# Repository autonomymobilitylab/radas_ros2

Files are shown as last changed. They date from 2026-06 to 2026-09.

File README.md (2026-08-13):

# Rugged ATV Data Acquisition System (RADAS)

### **Collaborators:**

 - [Aalto University Autonomy & Mobility Lab](https://www.aalto.fi/en/department-of-energy-and-mechanical-engineering/autonomy-mobility-lab): Joel Ventola, Otto Peltonen

# Overview

The Rugged ATV Data Acquisition System, or RADAS, is a versatile, rugged sensor rack designed to be mounted on the front cargo area of an ATV. With its modular design and small footprint, the system can also be mounted on other vehicles and platforms.

The purpose of this system is to collect real-world data for state-of-the-art (SOTA) datasets in unstructured off-road environments, such as forests and other off-road areas in Finland.

The system includes two different LiDAR sensors, three RGB cameras that provide a 170° field of view, a 9-DoF IMU, and an RTK-capable GNSS receiver. The system is also planned to be upgraded with an additional NIR (near-infrared) camera in the future.
The sensors and their specifications are listed in more detail in the table below.

### **Sensors**
 - 32-channel 360° LiDAR: [Hesai XT32M2X](https://www.hesaitech.com/product/xt16-32-32m/)
 - 128-channel dome LiDAR: [Hesai JT128](https://www.hesaitech.com/product/jt128/)
 - 3 x RGB-cameras: [Basler a2A1920-51gcBAS](https://www.baslerweb.com/en/shop/a2a1920-51gcbas/)
 - IMU: [Xsens MTi-320-3A-SK](https://www.xsens.com/sensor-modules/xsens-mti-320)
 - RTK-GNSS: [Ardusimple simpleRTK 4 Heading](https://www.ardusimple.com/product/simplertk-4-heading/)

# Guide
This guide contains information about many of the tools and procedures used during development. It does not necessarily reflect the final deployed system.

## **Prerequisites**

### **Software**
- [Ubuntu 24.04 LTS (Noble Numbat)](https://releases.ubuntu.com/noble/)
- [Docker 29.5.2, build 79eb04c](https://github.com/docker/docker-install)

### **Hardware**
- NUC/PC with adequite processing power, ram and storage space
- Network switch with 10GigE upstream and POE functionality
- Sensors listed in above table
- USB gpio breakout board and RGB led
- Power switch and power indicator led
- IP rated enclosure for electronics
- 12 to X volt converters for power
- Router for wireless access to the lan network
- Fusebox

## **Installation**
 1. Make sure you have the prerequisites listed above installed.

 2. Clone the repository and navigate to the `firmware` directory:

 ```shell
 git clone https://github.com/joevento/radas_ros2.git
 cd ./radas_ros2/firmware
 ```

 3. Create an .env with the following keys:
 ```text
 PROJECT_DIR=/full/path/to/radas_ros2/firmware/folder
 SERVICE_USER=user account to be used for systemctl
 PTP_INTERFACE=network interface for ptp
 NTRIPUSER=ntrip clients username (in finland use maanmittauslaitos username)
 NTRIPPASS=ntrip clients password (in finland use maanmittauslaitos password)
 ```

 4. Configure the NUC's network interface with the following static network settings:

    * **IP address:** `192.168.1.2`
    * **Subnet mask:** `255.255.255.0`

 5. Manually start the container to make sure everything works as intended:

 ```shell
 docker compose up --build
 ```

 6. Once the container has started successfully, navigate to `http://localhost:8080/` (or `http://192.168.1.2:8080/` when remote) to access the system's web interface. Each sensor is displayed in its own table, with a traffic light indicator in the first column showing its general status. Verify that all sensors show a green status.

 7. Once the system's functionality has been verified, stop the container using `Ctrl+C`.

 8. **(Optional)** Create an unprivileged user account under which the system will run.

 9. Regardless of whether you completed the optional step above, make sure the account used to run the system is automatically logged in at startup. This prevents the NUC from getting stuck on the login screen when the system is powered on.

    Automatic login can be enabled in the Ubuntu settings under:

    `System -> Users -> Automatic Login`

 > **Note:** If the Users page is grayed out, click the **"Unlock..."** button in the top-right corner.

 10. Once the functionality of the system has been verified manually, run the systemd service installation script from the `firmware` directory:

 ```shell
 ./install_service.sh
 ```

 The script installs and enables the systemd service responsible for starting the RADAS ROS 2 system automatically when the user logs in.

 11. Once the service has been installed successfully, restart the NUC and enter the BIOS (typically by pressing `F2` or `Del`). In the BIOS, enable automatic startup when power is restored.

     On the MS-01, this setting can be found under:

     `Advanced -> ACPI -> Restore Power on AC Power Loss`

     This ensures that the NUC boots and subsequently logs in automatically when the main power switch is turned on.

 12. Save the BIOS settings and exit. Allow the system to boot into Ubuntu, then navigate to `http://localhost:8080/` (or `http://192.168.1.2:8080/` when accessing remotely) and verify that all sensor status indicators are green.

 13. The system is now ready for use. From this point onward, it will automatically boot, log in, and start the RADAS ROS 2 system when the power switch on the side of the electrical cabinet is turned on.

 > **Note:** It has been measured that, from a cold and dark state, the system takes approximately two (2) minutes to start before data acquisition can begin.

## General Testing and Development Tools

### **Pylon Viewer Quick Start Outside of Docker**

 1. Run Pylon Viewer as root:

 ```shell
 sudo /opt/pylon/bin/pylonviewer
 ```

 2. Open the Pylon Viewer GigE Configurator:

    `Tools -> GigE Configurator`

    Select:

    `Optimize Complete System`

    Then click:

    `Configure`

 > **Note:** If Pylon Viewer does not detect the camera automatically, press `F12` or navigate to `Camera -> Add Remote GigE Camera` to add the camera manually.

 3. Reboot the system and relaunch Pylon Viewer to apply the configuration. The connected cameras should now be visible in Pylon Viewer.

### **Docker**

 1. Navigate to the `firmware` subdirectory:

 ```shell
 cd ./firmware/
 ```

 2. Build and start the Docker container in the background:

 ```shell
 docker compose up --build -d
 ```

 3. **(Optional)** To use GUI applications from inside the Docker container, allow local Docker containers to connect to the X server:

 ```shell
 xhost +local:docker
 ```

 > **Note:** When connecting to the system remotely via SSH, this command must be run on the local computer (e.g. laptop) before establishing the SSH connection.

 4. Open a shell inside the running container:

 ```shell
 docker compose exec ros2_dev /bin/bash
 ```

 ### **Starting the Main ROS 2 Package**

 1. Follow the Docker startup instructions above and open a shell inside the container.

 2. Inside the container, run:

 ```shell
 ros2 launch radas_bringup bringup.launch.py
 ```

 This launches the main RADAS ROS 2 bringup package.

 ### **LiDARs**

 #### **PandarView2**

 1. Make sure the device firewall is disabled or that the LiDAR UDP port (typically `2368`) is allowed through the firewall:

 ```shell
 sudo ufw disable
 sudo iptables -F
 ```

 > **Note:** Disconnecting and reconnecting the LiDAR may result in the firewall rules being reset, after which the port must be allowed through again.

 2. Check the IP address of the wired network interface:

 ```shell
 ip -br addr
 ```

 > **Note:** For troubleshooting or sanity-checking, you can verify that the connected LiDAR is sending UDP data using:
 >
 > `sudo tcpdump -i <NIC_device_name> -n udp port 2368`
 >
 > Alternatively, use Wireshark to inspect the network traffic.

 3. The default IP address of Hesai LiDARs is `192.168.1.201`. For models that support a web interface, navigate to this address in a browser to view and configure the LiDAR parameters.

    Models that do not support the web interface, such as the JT128, require Hesai's LidarUtilities software to view and modify their parameters.

 4. Launch PandarView2 and select `Listen for Data` (or press `Ctrl+R`). The host IP can either be set to `Any` or to the IP address of the wired network interface connected to the LiDAR.

 5. Once data is being received, import the corresponding angle correction file.

 #### **ROS 2 and RViz2**

 Use the same network configuration described in the PandarView2 section above.

 This guide does not cover creating the workspace, cloning the manufacturer's drivers/SDK, or installing ROS 2 package dependencies. Instead, it covers the most important configuration file changes required for the LiDARs.

 1. Configure the IP addresses in the LiDAR configuration file:

    - Set the **device IP address** to the address configured on the LiDAR.
    - Set the **host IP address** to the address of the wired network interface connected to the LiDAR.
    - Replace the **multicast IP address** with an empty string (`""`).

    All IP addresses should be specified as strings in the following format:

    ```text
    "192.168.1.xxx"
    ```

 2. Clear the following placeholder paths:

 ```yaml
 firetimes_path: ""
 ***
 channel_fov_filter_path: ""
 multi_fov_filter_ranges: ""
 ```

 3. Download the appropriate correction file for the LiDAR and configure its path. For example:

 ```yaml
 correction_file_path: "/home/user/hesai_ws/config/jt128_correction.csv"
 ```

 4. Make sure the required data is published through ROS 2:

 ```yaml
 ros:
    ros_frame_id: hesai_lidar
    ***
    send_packet_ros: true
    send_point_cloud_ros: true
    send_imu_ros: true
 ```

 5. Check the configured frame frequency. If it is set to `0`, change it to an appropriate value. For example:

 ```yaml
 frame_frequency: 10
 default_frame_frequency: 10.0
 ```

 6. Launch the LiDAR node and RViz2. To verify that the ROS 2 topics are available, run:

 ```shell
 ros2 topic list
 ```

 You should see LiDAR-related topics such as `/lidar_points`.

 Check the topic information and publishing frequency with:

 ```shell
 ros2 topic info /lidar_points
 ros2 topic hz /lidar_points
 ```

 `ros2 topic info /lidar_points` should return something similar to:

 ```text
 Type: sensor_msgs/msg/PointCloud2
 Publisher count: 1
 Subscription count: 0
 ```

 If `ros2 topic hz /lidar_points` does not return any data, ROS 2 is likely not receiving the LiDAR data stream.

 > **Note:** `ros2 topic hz` takes a few moments to calculate the publishing frequency, so do not expect an instantaneous result. With high data rates or large messages, the reported frequency may also be inaccurate. For troubleshooting purposes, the important thing is to verify that data is being received.

 ### **PTP**

 #### **Setting Up the NUC as a PTP Grandmaster**

 PTP is automatically configured when running:

 ```shell
 docker compose up --build -d
 ```

 The PTP service runs in a secondary container alongside the main ROS 2 container.

 To manually broadcast PTP from the device, for example for testing or troubleshooting, run:

 ```shell
 sudo ptp4l -i <device> -m -S
 ```

 The automatic PTP setup expects an `.env` file in the `./firmware` directory containing the network interface to use for PTP:

 ```text
 PTP_INTERFACE=<device>
 ```

 #### **LiDAR Timestamps**

 Both the JT128 and XT32M LiDARs use the same timestamp format in their data packets. The timestamp can be located manually from the raw packet data in Wireshark as follows:

 1. Starting from the end of the packet, locate the manufacturer magic value `42` in the raw Wireshark output.
 2. From `42`, move back 10 bytes (10 two-character hexadecimal byte values in Wireshark).
 3. The first byte represents `year - 1900`.
 4. The next five bytes represent, in order:
    `month, day, hour, minute, second`
 5. The final four bytes represent the microsecond component of the UTC timestamp.

 ### **SSH Access to the NUC**

 The MS-01 NUC is configured to accept SSH connections on the default SSH port. The connection details can be found physically on the machine.

 To connect to the NUC, use:

 ```shell
 ssh username@ip
 ```

 If X11 forwarding is required for graphical applications, add the `-X` option:

 ```shell
 ssh -X username@ip
 ```

 This guide does not cover the SSH server configuration itself, as the NUC uses a standard SSH server setup.

 #### **Syncing Local Changes During Development**

 For easier development, local changes can be pushed directly to the NUC using:

 ```shell
 ./firmware/sync_to_nuc.sh
 ```

 The script expects the following keys to be in your local .env file:
 ```
 REMOTE_USER=username on the nuc
 REMOTE_HOST=nuc ip address
 REMOTE_FIRMWARE_PATH=/full/path/to/radas_ros2/firmware/folder
 ```

 This allows changes made on the local development machine to be transferred to the NUC without first committing and pushing them through GitHub.

 This script should only be used during development and for quick testing. **Working, finalized code should always be committed to Git and pulled onto the NUC through the normal Git workflow.**

 Before pulling the finalized version on the NUC, discard changes previously transferred using the sync script:

 ```shell
 git restore .
 ```

 > **Warning:** `git restore .` discards uncommitted changes to tracked files. Make sure there are no changes on the NUC that need to be preserved before running this command.

 ### **Basler Cameras**

 Pylon Viewer can be used normally from inside the Docker container.

 For ROS 2 access to an individual Basler camera, the `pylon_ros2_camera_wrapper` package can be launched manually with:

 ```shell
 ros2 launch pylon_ros2_camera_wrapper pylon_ros2_camera.launch.py camera_id:="Basler_{pos}" config_file:="/ros2_ws/config/basler_{pos}.yaml"
 ```

 Replace `{pos}` with the position identifier of the camera.

 Running the camera wrapper this way is mainly useful for validating the broad functionality of the cameras inside ROS 2 and the container, as the standalone node does not provide much functionality by itself compared with the complete RADAS setup.

 ### **Running RADAS Automatically on Startup with systemd**

 The RADAS ROS 2 Docker stack can be started automatically using a systemd service.

 For this the `.env` file in the `firmware` directory should contain:

 ```shell
 PROJECT_DIR=/path/to/firmware/folder
 SERVICE_USER=localUser
 ```

 `PROJECT_DIR` should point to the RADAS `firmware` directory, and `SERVICE_USER` should be the local user account under which the system runs.

 #### **Installing the Service**

 Make the installation script executable and run it:

 ```shell
 chmod +x install_service.sh
 ./install_service.sh
 ```

 #### **Starting the Service Manually**

 ```shell
 sudo systemctl start radas_ros2.service
 ```

 #### **Viewing Logs**

 Follow the service logs in real time:

 ```shell
 journalctl -u radas_ros2.service -f
 ```

 #### **Restarting the Service**

 After making changes to the RADAS configuration or software, restart the service with:

 ```shell
 sudo systemctl restart radas_ros2.service
 ```

 #### **Disabling Automatic Startup**

 To prevent the service from starting automatically:

 ```shell
 sudo systemctl disable radas_ros2.service
 ```

 #### **Removing the Service**

 To completely remove the RADAS systemd service:

 ```shell
 sudo systemctl stop radas_ros2.service
 sudo systemctl disable radas_ros2.service
 sudo rm /etc/systemd/system/radas_ros2.service
 sudo systemctl daemon-reload
 ```

 ### **Status Page**

 The RADAS status page provides a web interface for monitoring sensor health, GNSS status, and controlling data recording.

 The page is normally started automatically as part of the RADAS Docker stack and can be accessed at:

 ```text
 http://localhost:8080
 ```

 or remotely from the RADAS network at:

 ```text
 http://192.168.1.2:8080
 ```

 #### **Diagnostics**

 Sensor health information is collected using the standard ROS 2 diagnostics pipeline:

```text
Sensor data / driver diagnostics
            |
            v
Sensor diagnostic nodes
            |
            v
      /diagnostics
            |
            v
 diagnostic_aggregator
            |
            v
    /diagnostics_agg
            |
            v
       RADAS Web UI
```

 Dedicated diagnostic nodes are used to normalize the status of the different sensor types before the information is passed to the diagnostic aggregator.

 The main sensor status table displays:

 - Traffic-light status indicator
 - Sensor name
 - Health level
 - Measured publishing frequency and expected frequency
 - Additional diagnostic details

 The traffic-light indicators represent:

 - 🟢 **Good**
 - 🟡 **Warning**
 - 🔴 **Error**
 - ⚫ **Stale / no current data**

 The expected sensor frequencies used by the status page are:

 ```text
 LiDAR:   10 Hz
 Camera:  10 Hz
 IMU:   100 Hz (fused)
 GNSS:    10 Hz
 ```

 For sensors with frequency information available, the web UI performs an additional check against the expected frequency:

 - **≥ 90%** of expected frequency: Good
 - **70–90%** of expected frequency: Warning
 - **≤ 70%** of expected frequency: Error

 The displayed health level is the more severe result of the diagnostic node's reported status and this frequency check.

 #### **Sensor Diagnostics**

 The cameras, LiDARs, IMU, and GNSS use separate diagnostic nodes.

 The **camera diagnostics** monitor the image streams of all three Basler cameras and combine their measured frame rate with the availability diagnostics produced by the Basler driver.

 The **LiDAR diagnostics** monitor the point cloud topics of both Hesai LiDARs and report their publishing frequency and stream status.

 The **IMU diagnostics** monitor the XSens IMU data stream and its publishing frequency.

 The **GNSS diagnostics** monitor the Septentrio GNSS receiver separately and provide more detailed positioning information to the web interface.

 #### **GNSS Status**

 GNSS information is displayed in a dedicated table containing:

 - Overall GNSS status
 - Positioning mode/status
 - Satellites used and visible
 - Latitude and longitude
 - Altitude
 - HDOP and PDOP
 - RF interference status
 - Spoofing status

 The GNSS diagnostic status also takes the positioning mode and availability of the required GNSS data streams into account. Detected interference or spoofing causes the GNSS diagnostic state to report an error.

 #### **System Status Indicator**

 In addition to the web interface, RADAS uses a physical status light connected through an FTDI GPIO interface.

 The light represents the overall diagnostic state of the system:

 - 🟢 **Green:** System OK
 - 🟡 **Yellow:** Warning
 - 🔴 **Red:** Error
 - 🔵 **Blue:** Diagnostics stale or unavailable

 The overall state is determined from the sensor and GNSS diagnostic states.

 #### **Recording Controls**

 The status page provides four controls for the ROS 2 system recorder:

 - **Start Recording**
 - **Pause Recording**
 - **Resume Recording**
 - **Stop Recording**

 These buttons communicate with the following ROS 2 services:

 ```text
 /system_recorder/record
 /system_recorder/pause
 /system_recorder/resume
 /system_recorder/stop
 ```

 The page also displays the current recording state and reports if a recorder request fails or the required ROS 2 service is unavailable.

 #### **Running the Status Page Manually**

 For development and testing, the web interface can be started manually.

 1. Create and activate a Python virtual environment:

 ```shell
 python3 -m venv .venv
 source .venv/bin/activate
 ```

 2. Install the required dependencies:

 ```shell
 pip install -r src/requirements.txt
 ```

 3. Make sure the ROS 2 environment and RADAS workspace are sourced:

 ```shell
 source /opt/ros/$ROS_DISTRO/setup.bash
 source install/setup.bash
 ```

 4. Start the diagnostic aggregator:

 ```shell
 ros2 run diagnostic_aggregator aggregator_node \
   --ros-args \
   --params-file diagnostic_aggregator.yaml
 ```

 5. Start the web server from another ROS-sourced terminal:

 ```shell
 python3 -m uvicorn src.webUI.app:app --host 0.0.0.0 --port 8080
 ```

 6. If accessing the web interface remotely, make sure TCP port `8080` is allowed through the firewall:

 ```shell
 sudo iptables -I INPUT 5 -p tcp --dport 8080 -j ACCEPT
 ```

 7. Open the web interface:

 ```text
 http://localhost:8080
 ```

 or, when accessing the NUC remotely:

 ```text
 http://192.168.1.2:8080
 ```

 #### **Troubleshooting**

 Check that raw diagnostics are being published:

 ```shell
 ros2 topic echo /diagnostics --once
 ```

 Check the output of the diagnostic aggregator:

 ```shell
 ros2 topic echo /diagnostics_agg --once
 ```

 The data currently received by the web UI can also be inspected directly:

 ```shell
 curl http://localhost:8080/diagnostics
 ```

 Other useful commands include:

 ```shell
 ros2 node list
 ros2 topic list
 ros2 topic hz <topic_name>
 ros2 service list
 ```

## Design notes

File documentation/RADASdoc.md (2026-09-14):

___
# RADAS user manual
This document is intended for the future use and development of the RADAS sensor rack by new users. This document is intended to fill the gaps left by the project README by serving as a general document on RADAS rather than a short bulletpoint list of setup steps. 

___
# Overview
The Rugged ATV Data Acquisition System (or RADAS) is a modular, plug-and-play sensor solution intended for capturing data in unstructured, forested areas. The purpose of this document is to provide a new user of the system with the expertise and know-how to initialize, operate and troubleshoot the system. 

The system is comprised of a central PC/NUC, 6 ethernet devices connected via a switch and 3 USB-devices. The devices used are:

| Device name | Device type | Connection to NUC |
| --- | --- | --- |
| Ubiquiti UniFi Flex 2.5G PoE | Switch | SFP |
| Basler a2A1920-51gcBAS | RGB Camera | RJ45 |
| Basler a2A1920-51gcBAS | RGB Camera | RJ45 |
| Basler a2A1920-51gcBAS | RGB Camera | RJ45 |
| Hesai XT32M2X | Hemispherical LIDAR  | RJ45 |
| Hesai JT128 | Dome LIDAR | RJ45 |
| Xsens MTi-320-3A-SK | IMU | USB |
| FTDI UM232H | USB to GPIO breakout | USB |
| Ardusimple SimpleRTK4 H | RTK GNSS-module | USB |

___
# Usage
### Powering the system
==TODO:== Attach pictures to all the steps described/of the full electrical connection diagram
The sensor rack only has 2 required connections to function: DC + and DC -. Powering the sensor rack happens via a DC input source, which can be a bench supply or an automotive auxiliary socket for example. The system accepts **12 V** at **20 A max**. 
>**Note:** the sensor rack browns out at around 9 V. As a result, it's critical that your DC source is stable and not susceptible to fluctuations. 

> **Note:** It is possible to power all the main components via their original AC adapters in troubleshooting scenarios. These AC adapters are not attached to the system, but they can be found at the lab instead. Doing this will bypass most of the elements, such as main power switch, power indicator lights and fusing described below

After the power has been connected, turn the main power switch from the position **OFF** to **ON** ==PICTURE HERE==

The system being powered should be indicated by the main power led turning on ==PICTURE HERE==

> **Troubleshoot:** If the main power led does not turn on or the rest of the system lacks all signs of life (LIDARs aren't audibly spinning, status led remains off) , check the main 20 A fuse inside the electrical cabinet. If it's blown, replace it. In other cases, check your power supply and finally change to powering the system via the AC adapters. 
### Recording via the provided Web UI
The ROS2 rosbag functionality is used to implement sensor output data recording. The recording is controlled via the Web UI with the labeled buttons on top of the page. Functionality is dead simple:
1. **```Start recording```** initializes a new rosbag and starts recording output data to a rosbag named ```system_recording_dd-mm-yy_hh-mm-ss``` which results in a uniquely named output rosbag based on recording time.
2. **```Pause recording```** pauses current recording, but does not finalize or close the current rosbag.
3. **```Resume recording```** continues paused recording to the same rosbag initialized with the last Start recording-command.
4. **```Stop recording```** stops the recording and finalizes and closes the current rosbag. After this, recording to the same rosbag is not possible and a new rosbag needs to be initialized via Start recording. 

Output data location on the NUC is **```/home/amlab/radas_ros2/firmware/output_data/rosbags```**
### Connecting to the system using a shell
The NUC is configured to accept SSH connections on the default SSH port. The connection details can be found physically on the machine.

To connect to the NUC, use (optionally if there is a need for a screen use -X flag):

```shell
ssh username@ip
```

### Finalizing the recording and turning off the system
Ending and closing the recording happens via pressing the **```Stop recording```** button in the Web UI. This safely finalizes and closes the current rosbag, after which the system can simply be powered off via flipping the main power switch. 

In case of a sudden shutdown of the system, the ROS 2 implementation of rosbag, the recording will still work due to using the MCAP-storage plugin, but all buffered frames will be lost, this will equal to around 5 frames. Reading the MCAP bag after an unexpected shutdown does require an external tool (not yet tested/covered). 
### Viewing and accessing the output data
The output data location on the NUC is **```/home/amlab/radas_ros2/firmware/output_data/rosbags```**. The saved rosbags can be played back using ```rosbag play system_recording.bag```, this results in all the ros messages sent during the recording to be replayed. It should be noted that due to ros2 performance limitations viewing the images in real time might result in choppy playback. To export the data from the bag a python script can be used. MCAP is also just a standard database format so the data can be accessed with typical db tools.
___
# Calibration
Calibration is an important step of in the operation of the system, but it isn't listed in the usage section as the sensor rack calibration has to be repeated only when the system changes: components are replaced or their positions are moved relative to each other. 

For both types of calibration, you will need the specific kind of calibration target suitable for the type of calibration. Both targets can be found at the garage.
### Intrinsic calibration
- Calibration target: checkerboard pattern target
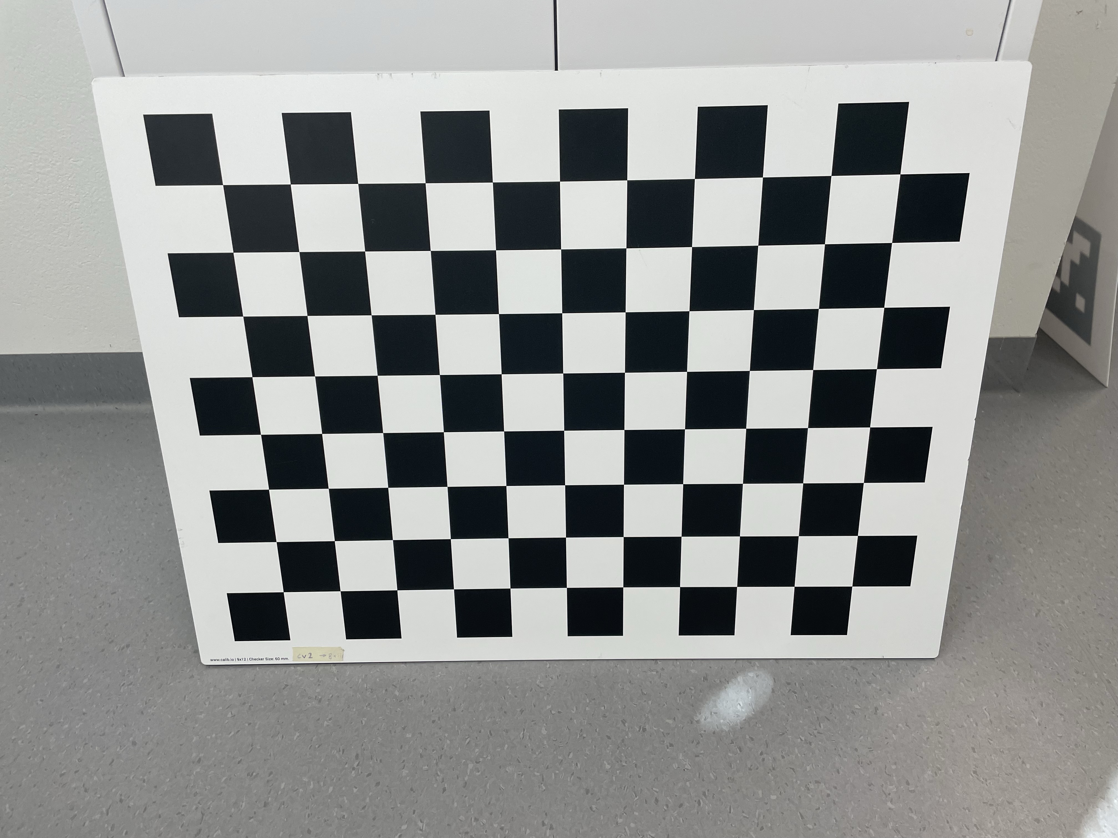
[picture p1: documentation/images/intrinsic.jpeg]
Image of intrinsic calibration target

Intrinsic calibration is used to determine the focal length, principal points and lens distortion of the cameras. Knowing these values, we can correct the lens distortion introduced especially by wide-FOV lenses to achieve a flatter, rectified image. 
### Extrinsic calibration
- Calibration target: target with ArUco Markers and 3 circular cutouts
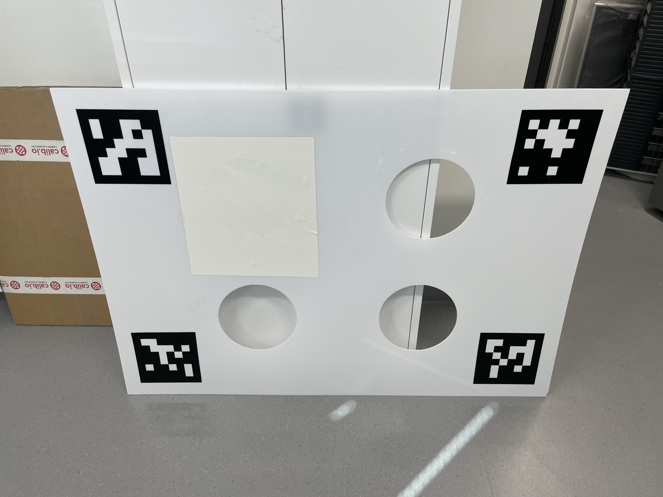
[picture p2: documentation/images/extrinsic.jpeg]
Image of extrinsic calibration targe


Extrinsic calibration is used to determine the translation and rotation matrices between the "root" sensor (XT32 LIDAR) and one of the 4 remaining sensors (JT128 LIDAR or Basler RGB cameras). Knowing these translation and rotation matrices between the sensors enables us to overlap and align their data ==PICTURE OF THE ALIGNED FRAMES==. 
>**Note:** You can use the big CTOUCH-screen located at the garage to have an easier time viewing your target positioning
___
# Software and operation overview
### Docker
Docker containerization is used 

### ROS 2

### Sensor triggering and synchronization
- **Sensor clock source:**
The most fundamental aspect of data frame alignment and sensor synchronization is the synchronization of their internal clocks used for timestamping each frame. To achieve this, RADAS uses the IEEE 1588-standard **Precision Time Protocol** (later PTP). The main PC/NUC of the system serves as the PTP-GM, the main clock which is used to serve time to other devices. We use hardware timestamping, because the NUC features a built-in network interface card supporting the protocol. Not being connected to UTC-time is not a problem, because the local PC time is the same for all sensors after slaving them to the PC.
- **Slaving sensors to the PTP-GM**
PTP's delay requests and responses, used for controlling the slave clock, can natively be transmitted only over ethernet, and thus it's served only to our ethernet-connected devices. The system's cameras are configured to enable PTP as their clock source during our driver launch, while the LIDARS are configured to use PTP through the lidarutilities-software/manufacturer web UI. ==EXPAND THIS, WITH PICTURES FOR EXAMPLE==
- **Camera trigger source**
We utilize the camera's ability to receive external hardware trigger signals. This signal is provided by the Ardusimple GNSS-module. To configure this signal, it's possible to use the manufacturer's RxControl-software under ==INSERT PATH HERE==. 
___
# Troubleshooting
### Viewing container/ROS 2 logs
As the container is started as a systemd service viewing the logs live requires some extra tinkering. For this journalctl has to be used and the command for it is ```sudo journalctl -u radas_ros2.service -f```. The logs are also written into the current_boot.log file found in /logs along with the file for the previous bootup.

### Using the manufacturer device software
- **RGB-Cameras: Basler PylonVIewer**

- **LIDARS: Hesai Lidautilities, webUI and Pandarview**

- **GPS: RxControl**

### Not receiving data from LIDARS
First things first make sure the nuc firewall is not blocking the communications. The lidar knows how to reply to pings so one can simply ping it to see if its alive and able to reply back. Wireshark (or similar) can be used to inspect the network traffic, filtering it to the ip of the lidar can be used to inspect the messages being sent.

### Not receiving data from cameras

### Not receiving data from IMU/GPS
___
# Misc
### Adding new or replacing old components

The current sensor rack system is very modular. The aluminium profile assembly allows easy modification of the current structure with the software being modular through the containerization of the software.  There are a few important points for adding new components to the current system. These include accessing the device and device drivers.

- **Accessing the device**
For ethernet-connected devices, it's important that the data-packets sent by the device are not blocked by the NUC firewall. on our NUC, ```sudo iptables -F``` can be used to temporarily allow data-packets to arrive at the PC, but it is advisable to find out to which port the new sensor sends data and permanently allow that port through in your firewall rules. The iptable-rules can reset upon network connection reset, such as disconnecting and reconnecting the device.

USB devices have 1 similar detail to look out for. The device might belong to a specific user group, and if your user is not a part of it, you will not be able to access or use the devices. For example the IMU and GPS-modules both belong to the ```dialout```-group, and you have to modify your user's access rights to be able to use these devices. This modification has already been implemented on the system's NUC, but future devices could use different groups. 

- **Device drivers**
There is 1 simple test you can do before even buying a new device for the system. Add the new device drivers to the current Dockerfile and attempt to build the container. The build being successful is not a full guarantee of the sensor compatibility, but the build failing is a sure indicator that the drivers have to be figured out before purchasing said part.
___

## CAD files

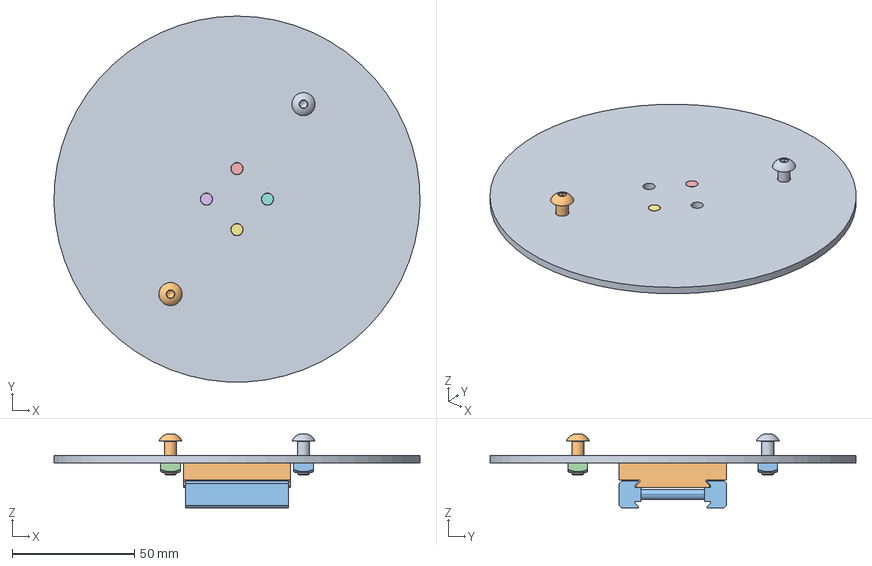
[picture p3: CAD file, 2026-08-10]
hardware/CAD_joel/ublox_antenna_assembly.FCStd
149.9 x 149.9 x 30.1 mm
M5x14-Screw x 2
M5x14-Screw001 x 2
M5-Nut x 2
M5-Nut003 x 2
M6x10-Screw x 2
M6x10-Screw010 x 2
M6x10-Screw011 x 2
M6x10-Screw012 x 2
Adapterplatte_Parallel_Senkrecht
Parallelklemme_Lang_30mm

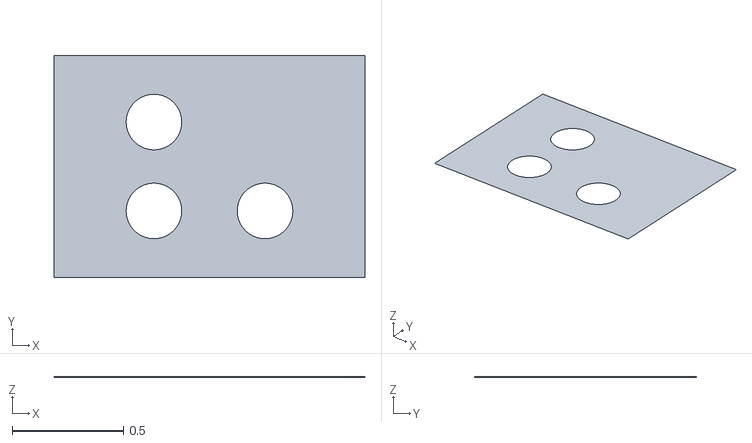
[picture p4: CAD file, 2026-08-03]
firmware/config/calibration/Radas_calibration_target_mesh_3hole.ply
1.40 x 1.00 x 0.003

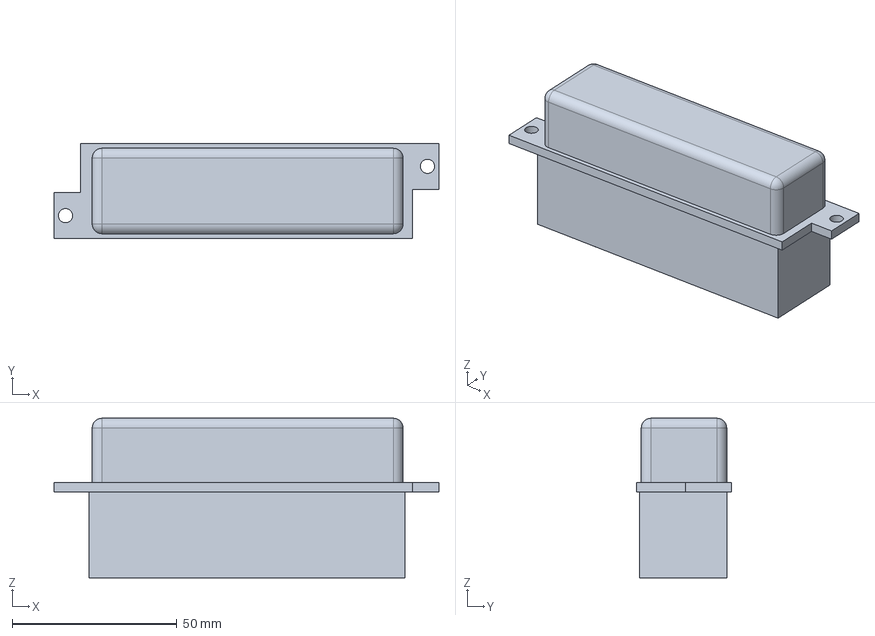
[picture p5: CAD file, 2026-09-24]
hardware/CAD_joel/fusebox.FCStd
117.0 x 29.0 x 48.5 mm

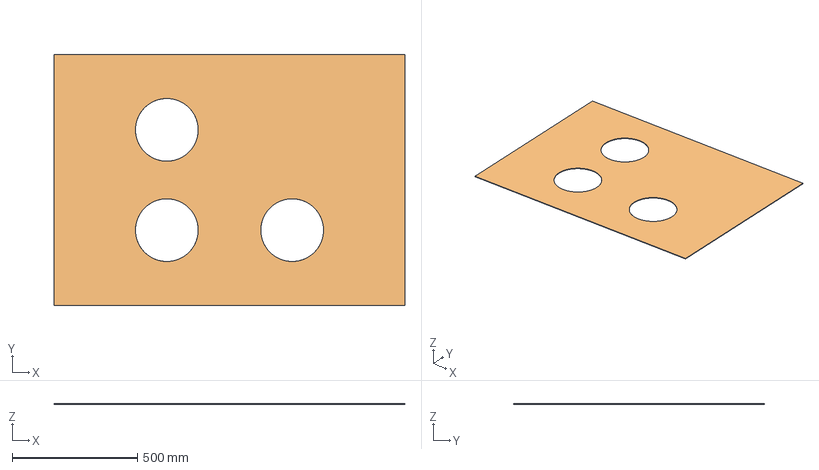
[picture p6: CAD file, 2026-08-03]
hardware/Calibration_target/Calibration_target.FCStd
1400.0 x 1000.0 x 3.00 mm
3_hole
3_hole (Meshed)

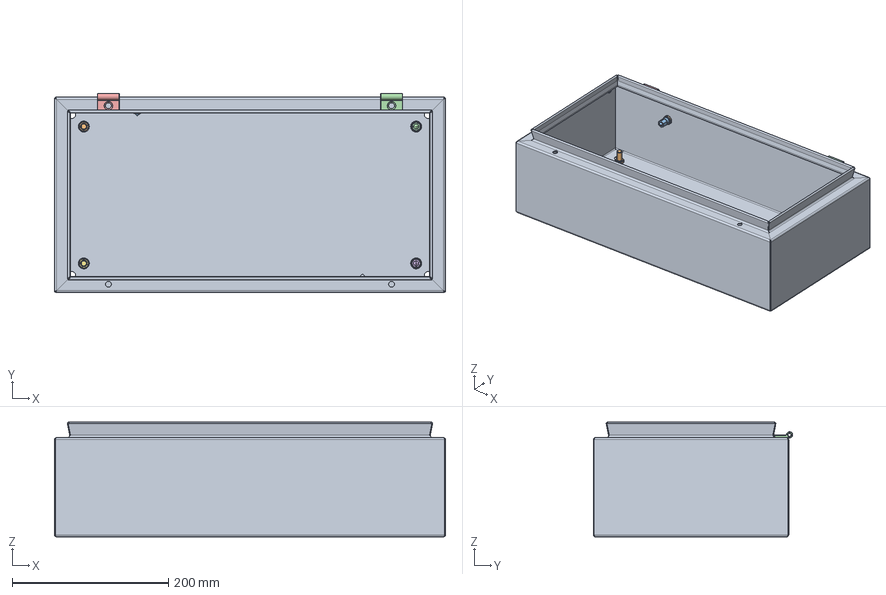
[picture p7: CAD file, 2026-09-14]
hardware/model_lib/YA_elec_cabinet.FCStd
500.0 x 255.0 x 146.8 mm
ENN0071AS_250X500
51140583-S01
51140583-S001
ENN2538A_M8X001
51140583-S002
ENN2538A_M8X002
51140583-S003
51140582-S01
ENN2538A_M6X17
51140582-S001
ENN2538A_M6X001
ENN1111AS
ENN1111AS001

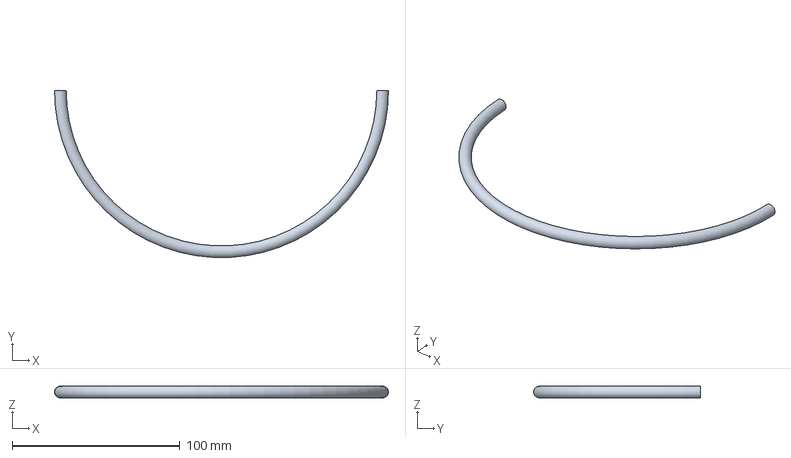
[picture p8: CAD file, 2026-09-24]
hardware/CAD_joel/dome_guard.FCStd
199.0 x 99.4 x 7.00 mm

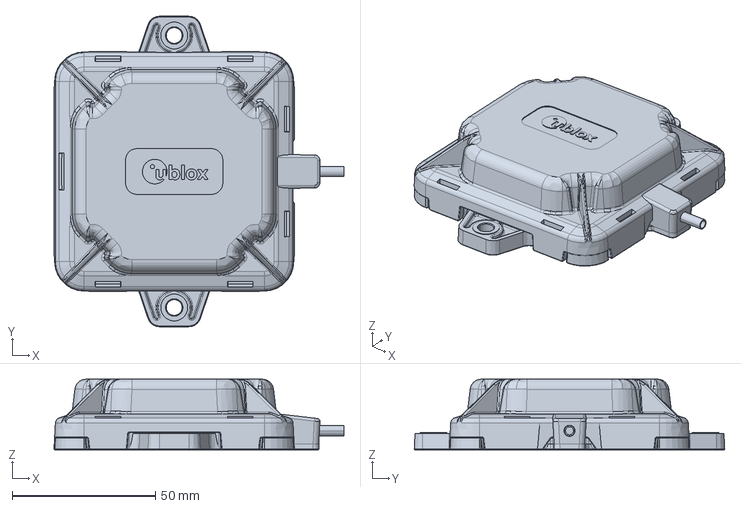
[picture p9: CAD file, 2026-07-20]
hardware/model_lib/Ublox_antenna.FCStd
101.3 x 108.5 x 24.7 mm

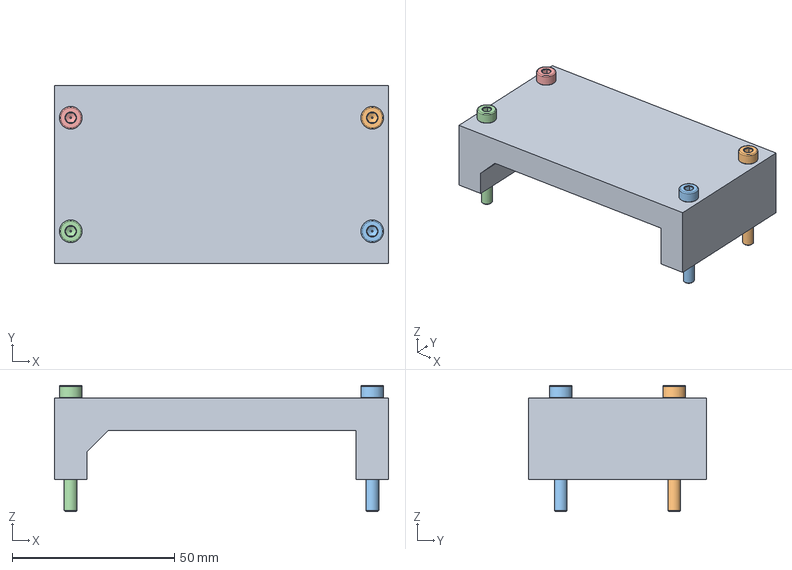
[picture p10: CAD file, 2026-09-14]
hardware/CAD_joel/router_mount.FCStd
103.0 x 55.0 x 39.0 mm
M4x35-Screw x 2
M4x35-Screw055 x 2
M4x35-Screw056 x 2
M4x35-Screw057 x 2

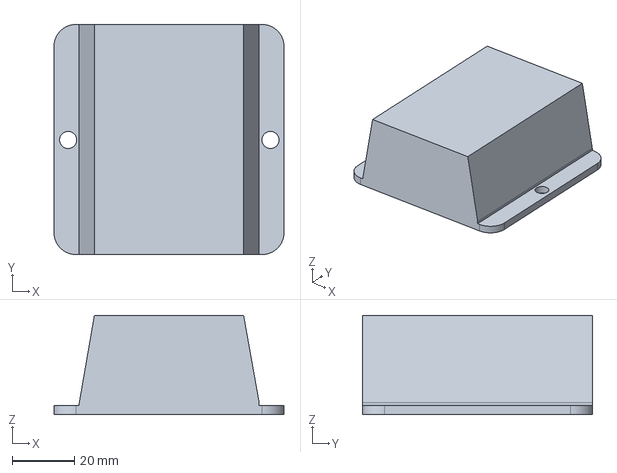
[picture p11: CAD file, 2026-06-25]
hardware/model_lib/DC-DC_square.FCStd
74.0 x 74.0 x 32.0 mm

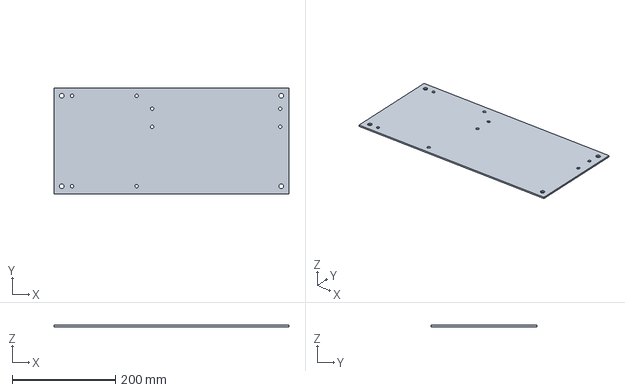
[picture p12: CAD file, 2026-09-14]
hardware/CAD_joel/base_mount_plate.FCStd
455.0 x 205.0 x 3.00 mm

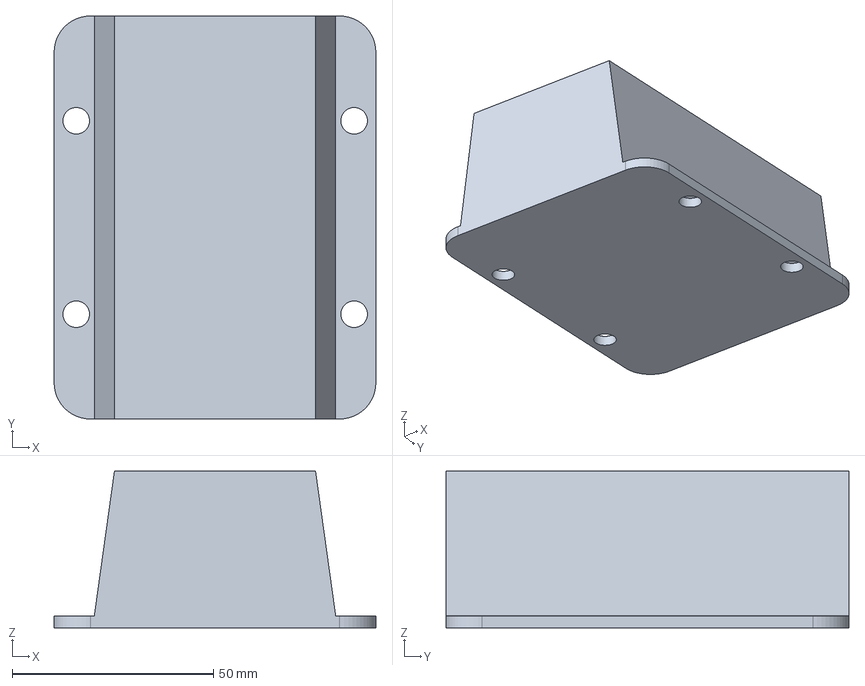
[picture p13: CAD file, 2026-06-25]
hardware/model_lib/DC-DC_rectangle.FCStd
80.0 x 100.2 x 39.0 mm

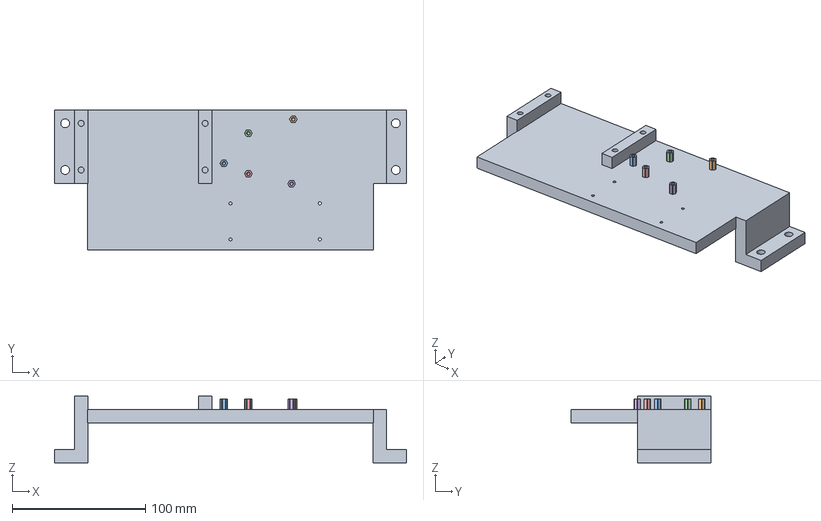
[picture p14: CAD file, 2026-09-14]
hardware/CAD_joel/switch_mount.FCStd
264.0 x 105.0 x 50.0 mm
M3x8x5-Standoff x 2
M3x8x5-Standoff265 x 2
M3x8x5-Standoff266 x 2
M3x8x5-Standoff267 x 2
M3x8x5-Standoff268 x 2

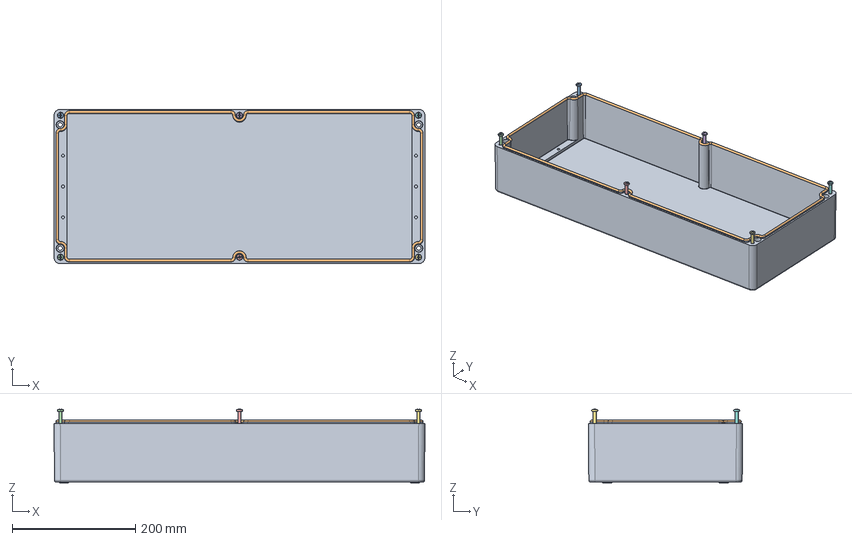
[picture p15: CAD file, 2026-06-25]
hardware/model_lib/Electronics_box.FCStd
601.2 x 250.2 x 119.5 mm
1590ZGRP263BK box
1590ZGRP263 GASKET
(screw M6-1X 30mm PN)
(screw M6-1X 30mm PN)001
(screw M6-1X 30mm PN)002
(screw M6-1X 30mm PN)003
(screw M6-1X 30mm PN)004
(screw M6-1X 30mm PN)005

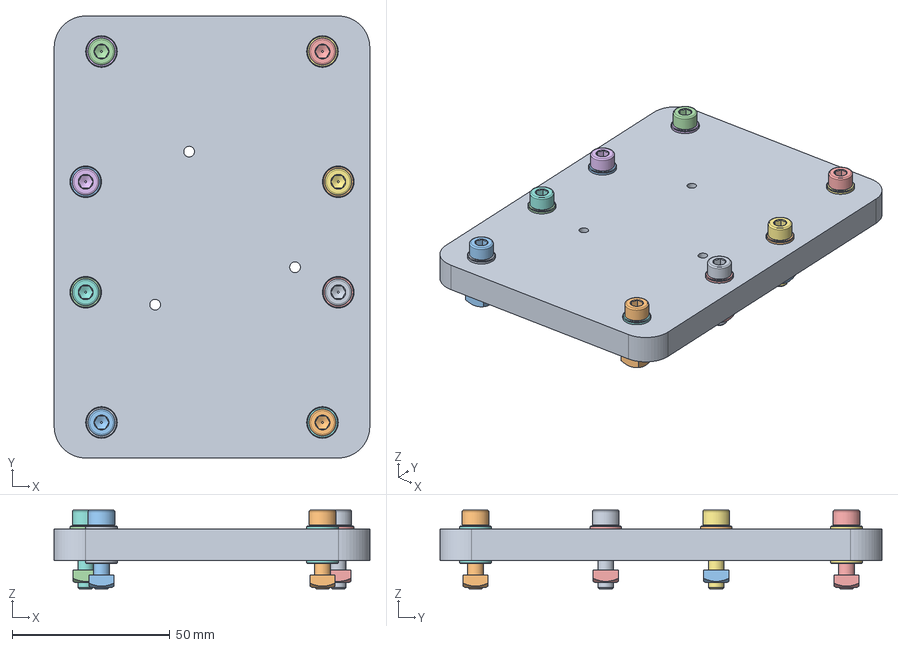
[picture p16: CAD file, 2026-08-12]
hardware/CAD_joel/Jt_guard_mount.FCStd
100.0 x 140.0 x 25.0 mm
M5-Washer x 2
M5-Washer258 x 2
M5-Washer259 x 2
M5-Washer260 x 2
M5x20-Screw x 2
M5x20-Screw146 x 2
M5x20-Screw147 x 2
M5x20-Screw148 x 2
M5-Nut x 2
M5-Nut170 x 2
M5-Nut171 x 2
M5-Nut172 x 2
M5-Washer261 x 2
M5-Washer262 x 2
M5-Washer263 x 2
M5-Washer264 x 2
M5x20-Screw149 x 2
M5x20-Screw150 x 2
M5x20-Screw151 x 2
M5x20-Screw152 x 2
M5-Washer265 x 2
M5-Washer266 x 2
M5-Washer267 x 2
M5-Washer268 x 2
M5-Nut173 x 2
M5-Nut174 x 2
M5-Nut175 x 2
M5-Nut176 x 2

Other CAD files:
hardware/model_lib/1.1063_paatysuoja.FCStd
hardware/CAD_joel/Hesai_jt128_mount.FCStd
hardware/model_lib/Autovimation_colibriS.FCStd
hardware/CAD_joel/converter_mount.FCStd
hardware/CAD_joel/Basler_mount_front_NIR.FCStd
hardware/CAD_joel/Hesai_xt32_mount.FCStd
hardware/CAD_joel/Low_poly_aluminum_extrusions.FCStd
hardware/CAD_joel/Xsens_enclosure-Xsens_enclosure_base.step
hardware/CAD_joel/Xsens_enclosure-Xsens_enclosure_lid.step
hardware/CAD_joel/Xsens_enclosure.FCStd
hardware/CAD_joel/basler_mount.FCStd
hardware/CAD_joel/basler_mount_front_v2.FCStd
hardware/CAD_joel/basler_mount_left.FCStd
hardware/CAD_joel/basler_mount_left_v2.FCStd
hardware/CAD_joel/basler_mount_right.FCStd
hardware/CAD_joel/basler_mount_right_v2.FCStd
hardware/CAD_joel/dome_angle_mount.FCStd
hardware/CAD_joel/dome_angle_mount_2.FCStd
hardware/CAD_joel/nuc_mount_bottom.FCStd
hardware/CAD_joel/nuc_mount_top.FCStd
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

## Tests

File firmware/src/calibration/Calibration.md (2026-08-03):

# Calibration

## Intrinsic Calibration

This project uses Vincent Rabaud's [ROS camera calibration package](https://wiki.ros.org/camera_calibration) together with a custom shell script, `camera_intrinsics_calibration.sh`, and a calib.io calibration target.

### Launch and Usage

Run the `camera_intrinsics_calibration.sh` script. It will prompt you to select the camera to calibrate:

```shell
Enter camera position ['left', 'middle', 'right'] to calculate intrinsics for:
```

Enter the desired camera position and press **Enter**.

The calibration GUI will then open in a single window. Move the calibration board so the entire 8×11 calibration target is visible from different positions and angles. Make sure to also rotate the board about its roll and pitch axes. As sufficient calibration data is collected, the progress bars on the right side of the GUI will fill.

Once all progress bars are full, the **CALIBRATE** button becomes available. Click it and wait for the optimization to finish. The GUI may become temporarily unresponsive while the calibration is being computed.

After the optimization completes, the **SAVE** and **UPLOAD** buttons will become available.

> **Warning**
> Do **not** click **UPLOAD**. This feature attempts to upload the calibration directly to the camera, but it is not supported by the Basler driver. Clicking it will cause the GUI to freeze and your calibration results will be lost.

Click **SAVE** to write the calibration results to a temporary file. You can preview the calibration results in the GUI before closing it.

When you are satisfied with the results, close the GUI. The terminal running the script will ask whether you want to overwrite the existing calibration parameters for the selected camera.

Press any key to overwrite the existing parameters, or press **Ctrl+C** to cancel.

If confirmed, the new calibration parameters will replace the existing files located at:

```text
/ros2_ws/config/intrinsics/{camera_pos}/
```

## Extrinsic Calibration
For extrinsic calibration, this project uses the FraunhoferIOSB [multisensor calibration toolbox](https://github.com/FraunhoferIOSB/multisensor_calibration) with a custom shell script ```launch_extrinsic_calibration.sh``` and a custom calibration target. 

### Launch and usage
The custom shell script ```launch_extrinsic_calibration.sh``` queries the user on the preferred calibration type:
```shell
Select calibration type:
1) LIDAR-to-LIDAR
2) LIDAR-to-Camera
Enter 1 or 2: 
```
Both calibration types use the hemispherical LIDAR XT32 as their reference. 
#### 1): LIDAR-to-LIDAR
After selecting 1, the extrinsic calibration toolbox will launch a GUI with 4 windows (from left-to-right, up-to-down):
1. A control window displaying calibration progress and console logs.
2. A window displaying calibration target placement guidance. **THIS FEATURE IS NOT FULLY DEVELOPED YET, DON'T USE IT**.
3. Target LIDAR view.
4. Source LIDAR view.

Once the toolbox has booted and you can see live feed from both LIDARS, place the calibration target in view of both LIDARS so that it's highlighted. 
From here, press **Capture Target Observation**. After this, the target will be highlighted in yellow with different colors of dots marking the corners of the AruCo-targets. Ensure that this highlighting is identical between the two lidars. If not, press **Remove Last Observation**.
#### 2) LIDAR-to-Camera:
After selecting 2, the shell script will promp the user to choose camera position to calibrate:
```shell
Choose camera to calibrate ['left', 'middle', 'right']: 
```
Enter your preferred camera and press enter. After this the toolbox will launch the calibration GUI. Different from LIDAR-to-LIDAR calibration is that the calibration target placement guidance on the upper right corner of the screen actually works. Follow its instructions on target placement. 

Once the target is in place, press **Capture Target Observation**. If the corners between the LIDAR and camera view don't match, press **Remove Last Observation** and repeat the process.

Continue this process for atleast 5 different observations, holding the target in a different orientation, different position of the LIDAR's/Camera's FOV. If the toolbox gets stuck after capturing target observation, try moving around to a new location with the target. If this doesn't resolve after a while, kill the process and start again. 

After enough suitable target observations, press **Calibrate**. This will print out the calibration results to the console, but this is also saved to the location ```firmware/config/last_observation.yaml``` (for LIDARs) or ```firmware/config/extrinsics/[camera_pos]``` (for cameras). 

**Inspecting calibration results**

### Custom calibration target 
The calibration target is configured and defined with the following files:
```
Radas_calibration_target_cloud_3hole.ply
Radas_calibration_target_mesh_3hole.ply
TargetWithCirclesAndAruco.yaml
```
All of these files are located in the folder ```firmware/config```

To configure the toolbox to use a different calibration target, follow [these](https://fraunhoferiosb.github.io/multisensor_calibration/calibration_target/#using-a-custom-calibration-target) instructions from the calibration toolbox documentation. In addition to the ```.yaml``` configuration file, you have to adapt the target cloud and mesh in cad to match the used target.

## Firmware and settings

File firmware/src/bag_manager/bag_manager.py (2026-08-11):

import rclpy
from rclpy.node import Node
from rclpy.serialization import serialize_message

from sensor_msgs.msg import PointCloud2, Image, CameraInfo, MagneticField
from geometry_msgs.msg import Vector3Stamped
from gps_msgs.msg import GPSFix
from tf2_msgs.msg import TFMessage

import gc
from datetime import datetime
from pathlib import Path
from threading import Lock

import rosbag2_py
from rosbag2_interfaces.srv import Pause, Resume, Record, Stop

class SystemRecorder(Node):
    def __init__(self):
        super().__init__('system_recorder')

        self.writer = None
        self.recording = False
        self.paused = False
        self.writer_lock = Lock()

        self.bag_root = Path('/data/rosbags')
        self.bag_root.mkdir(parents=True, exist_ok=True)

        # The list of all recorded topics
        self.topics = {
            PointCloud2: [
                '/lidar_points_xt',
                '/lidar_points_jt',
            ],
            Image: [
                '/Basler_left/pylon_ros2_camera_node/image_raw',
                '/Basler_middle/pylon_ros2_camera_node/image_raw',
                '/Basler_right/pylon_ros2_camera_node/image_raw',
            ],
            CameraInfo: [
                '/Basler_left/pylon_ros2_camera_node/camera_info',
                '/Basler_middle/pylon_ros2_camera_node/camera_info',
                '/Basler_right/pylon_ros2_camera_node/camera_info',
            ],
            Vector3Stamped: [
                '/imu/acceleration_hr',
                '/imu/angular_velocity_hr',
            ],
            MagneticField: ['/imu/mag'],
            GPSFix: ['/Gnss/gpsfix'],
            TFMessage: ['/tf'],
        }

        self.bag_subscriptions = []
        self.create_control_services()
        self.create_bag_subscriptions()

        self.get_logger().info('System recorder node started.')
        self.get_logger().info('Recorder is idle. Call /system_recorder/record to start recording.')

    # Creation of services which are used to control the bag recordings
    def create_control_services(self):
        self.record_service = self.create_service(
            Record,
            '~/record',
            self.record_callback
        )
        self.stop_service = self.create_service(
            Stop,
            '~/stop',
            self.stop_callback
        )
        self.pause_service = self.create_service(
            Pause,
            '~/pause',
            self.pause_callback
        )
        self.resume_service = self.create_service(
            Resume,
            '~/resume',
            self.resume_callback
        )

    def create_bag_subscriptions(self):
        for msg_type, topic_names in self.topics.items():
            for topic_name in topic_names:
                sub = self.create_subscription(
                    msg_type,
                    topic_name,
                    lambda msg, topic_name=topic_name: self.write_msg(topic_name, msg),
                    10
                )

                self.bag_subscriptions.append(sub)

    def record_callback(self, request, response):
        with self.writer_lock:
            if self.recording:
                self.get_logger().warn('Record request rejected: recorder is already recording.')

                self.set_service_response(
                    response, 
                    success=False,
                    message='Recorder is already recording.'
                )
                return response

            requested_uri = getattr(request, 'uri', '')

            if requested_uri:
                bag_path = Path(requested_uri)

                # If the user gives only a bag name, place it under /data.
                if not bag_path.is_absolute():
                    bag_path = self.bag_root / bag_path
            else:
                # If no URI is given, create a unique recognizable name.
                bag_name = datetime.now().strftime('system_recording_%Y-%m-%d_%H-%M-%S')
                bag_path = self.bag_root / bag_name

            try:
                self.open_bag(bag_path)

                self.recording = True
                self.paused = False

                self.get_logger().info(f'Recording started: {bag_path}')

                self.set_service_response(
                    response,
                    success=True,
                    message=f'Recording started: {bag_path}'
                )

            except Exception as exc:
                self.writer = None
                self.recording = False
                self.paused = False

                self.get_logger().error(f'Failed to start recording: {exc}')

                self.set_service_response(
                    response,
                    success=False,
                    message=f'Failed to start recording: {exc}'
                )

            return response

    def stop_callback(self, request, response):
        with self.writer_lock:
            if not self.recording:
                self.get_logger().warn('Stop request rejected: recorder is not recording.')

                self.set_service_response(
                    response,
                    success=False,
                    message='Recorder is not recording.'
                )
                return response

            try:
                self.close_bag()

                self.recording = False
                self.paused = False

                self.get_logger().info('Recording stopped.')

                self.set_service_response(
                    response,
                    success=True,
                    message='Recording stopped.'
                )

            except Exception as exc:
                self.get_logger().error(f'Failed to stop recording: {exc}')

                self.set_service_response(
                    response,
                    success=False,
                    message=f'Failed to stop recording: {exc}'
                )

            return response

    def pause_callback(self, request, response):
        with self.writer_lock:
            if not self.recording:
                self.get_logger().warn('Pause request rejected: recorder is not recording.')
                self.set_service_response(
                    response,
                    success=False,
                    message='Recorder is not recording.'
                )
                return response

            if self.paused:
                self.get_logger().warn('Pause request rejected: recorder is already paused.')
                self.set_service_response(
                    response,
                    success=False,
                    message='Recorder is already paused.'
                )
                return response

            self.paused = True
            self.get_logger().info('Recording paused.')
            self.set_service_response(
                response,
                success=True,
                message='Recording paused.'
            )

            return response

    def resume_callback(self, request, response):
        with self.writer_lock:
            if not self.recording:
                self.get_logger().warn('Resume request rejected: recorder is not recording.')
                self.set_service_response(
                    response,
                    success=False,
                    message='Recorder is not recording.'
                )
                return response

            if not self.paused:
                self.get_logger().warn('Resume request rejected: recorder is not paused.')
                self.set_service_response(
                    response,
                    success=False,
                    message='Recorder is not paused.'
                )
                return response

            self.paused = False
            self.get_logger().info('Recording resumed.')
            self.set_service_response(
                response,
                success=True,
                message='Recording resumed.'
            )

            return response
        
    def open_bag(self, bag_path: Path):
        bag_path.parent.mkdir(parents=True, exist_ok=True)
        self.writer = rosbag2_py.SequentialWriter()

        storage_options = rosbag2_py.StorageOptions(
            uri=str(bag_path),
            storage_id='mcap'
        )

        converter_options = rosbag2_py.ConverterOptions('', '')
        self.writer.open(storage_options, converter_options)
        self.create_bag_topics()

    def close_bag(self):
        if self.writer is None:
            return

        if hasattr(self.writer, 'close'):
            self.writer.close()

        self.writer = None
        gc.collect()

    def create_bag_topics(self):
        if self.writer is None:
            raise RuntimeError('Cannot create bag topics because writer is not open.')

        for msg_type, topic_names in self.topics.items():
            type_name = self.get_ros_type_name(msg_type)

            for topic_name in topic_names:
                topic_info = rosbag2_py.TopicMetadata(
                    id=0,
                    name=topic_name,
                    type=type_name,
                    serialization_format='cdr'
                )

                self.writer.create_topic(topic_info)

    def write_msg(self, topic_name, msg):
        with self.writer_lock:
            if not self.recording:
                return

            if self.paused:
                return

            if self.writer is None:
                return

            timestamp = self.get_clock().now().nanoseconds

            self.writer.write(
                topic_name,
                serialize_message(msg),
                timestamp
            )

    @staticmethod
    def get_ros_type_name(msg_type):
        package = msg_type.__module__.split('.')[0]
        return f'{package}/msg/{msg_type.__name__}'

    @staticmethod
    def set_service_response(response, success=None, message=None):
        """
        Different ROS 2 versions may expose slightly different service response fields.
        This helper sets fields only if they exist.
        """
        if success is not None and hasattr(response, 'success'):
            response.success = success

        if message is not None and hasattr(response, 'message'):
            response.message = message


def main():
    rclpy.init()

    node = SystemRecorder()

    try:
        rclpy.spin(node)
    finally:
        if node.recording:
            node.get_logger().info('Node shutting down while recording. Closing bag.')
            node.close_bag()

        node.destroy_node()
        rclpy.shutdown()

if __name__ == '__main__':
    main()

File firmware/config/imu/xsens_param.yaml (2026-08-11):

/**:
    ros__parameters:
        # Device Scanning Configuration
        # -----------------------------
        # This section allows you to configure how the ROS driver searches for devices.
        # You have two options:
        # 1. Automatic scanning for devices.
        # 2. Manual specification of port and baudrate.

        # Option 1: Automatic Device Scanning
        # If set to 'true', the driver will ignore 'port' and 'baudrate' settings.
        # It will automatically scan all ports and select the first device found.
        scan_for_devices: true

        # Option 2: Manual Device Configuration
        # If you prefer to manually specify the device port and baudrate,
        # first set 'scan_for_devices' to 'false', then uncomment and update
        # the 'port' and 'baudrate' settings below according to your device's specifications.
        #
        # To find your device's port, you can use the command: ls -l /dev/ttyUSB*
        #
        # Default baudrate is 115200. You can also use external tools like MT Manager
        # or Cutecom for baudrate configuration. For example, 
        # to set baudrate to 115200, send the command: FA FF 30 00 D1, 
        # or to set it to 921600, send: FA FF 18 01 80 68.

        # port: '/dev/ttyUSB0' # Uncomment and set your device's port.
        # baudrate: 921600     # Uncomment and set your device's baudrate.

        # Device Scanning Selection
        # ----------------
        # Specify the device ID when operating multiple devices to select a specific one.
        # Format: Uppercase hexadecimal string.
        # Example: device_id: '00800210C2'
        #device_id: '00800210C2'

        # Publisher Configuration
        publisher_queue_size: 5

        # Time Options
        # ------------
        # Choose how timestamps are generated for the ROS Node:
        # 1) 0: Use UTCTime from MTI, recommended for accurate time synchronization.
        # 2) 1: Use UTCTime based on the SampleTimeFine from MTI.
        # 3) 2: Use UTCTime from the host device.
        # Note: Ensure "UTC Time" or "Sample Time Fine" is selected in MT Manager under Device Settings > Output Configurations, 
        # or you could also set 'enable_deviceConfig: true' for once to configure output.
        time_option: 3

        # Logging Configuration
        # ---------------------
        # Enable or disable logging of sensor data into .mtb file. If enabled, logs are stored in /home/[user_name]/Documents/xsens_log.
        enable_logging: false

        # Transform Frame ID
        # ------------------
        # Default frame_id is "imu_link". Change this if using multiple devices to avoid conflicts.
        # frame_id: "imu_link"


        # Sensor Configuration
        # ---------------------------
        # If you want to configure your sensor, firstly set this flag to true, then change desired values for the parameters below.
        # Note: This configuration is required only once, once it is successful, the configurations are stored in the sensor, then you could set this to false.
        enable_deviceConfig: true

        # Sensor Extended Kalman Filter Option Configurations:
        # --------------------------
        # ref: https://base.movella.com/s/article/article/MTi-Filter-Profiles-1605869708823
        # If you want to configure the filter option, firstly set the 'enable_filter_config', then:
        # For MTi-3/7/8/30/300/G-710/670(G)/680(G): change the 'mti_filter_option' to desired index below for your model.
        # For MTi-620(R)/MTi-630(R), and Sirius/Avior VRU/AHRS models:   change the 'filter_label_rollpitch' and 'filter_label_yaw' to the exact labels.
        enable_filter_config: false
        # ---------------------------
        # For MTi-670(G): 3 options: 0 = "General", 1 = "GeneralNoBaro", 2 = "GeneralMag"
        # For MTi-680(G), 3 options: 0 = "General_RTK", 1 = "GeneralNoBaro_RTK", 2 = "GeneralMag_RTK"
        # For MTi-3: 4 options: 0 = "general", 1 = "high_mag_dep", 2 = "dynamic", 3 = "north_reference", 4 = "vru_general"
        # For MTi-320: 1 option: 0 = "vru_general"
        # For MTi-7:  3 options: 0 = "General", 1 = "GeneralMag",  2 = "GeneralNoBaro"
        # For MTi-8: 3 options: 0 = "General_RTK", 1 = "GeneralNoBaro_RTK", 2 = "GeneralMag_RTK"
        # For MTi-300: 0 = "general", 1 = "high_mag_dep", 2 = "dynamic", 3 = "lwo_mag_dep", 4 = "vru_general"
        # For MTI-G-710: 3 options: 0 = "General", 1 = "GeneralNoBaro",  2 = "GeneralMag", 3 = "Automotive", 4 = "HighPerformanceEDR"
        mti_filter_option: 0

        # For MTi-620(R)/MTi-630(R), and Sirius/Avior VRU/AHRS models:  roll pitch options: "Responsive", "General", "Robust"
        filter_label_rollpitch: "Robust"
        # MTI-620(R) and Sirius/Avior VRU models, yaw has 2 options: "VRU", "VRUAHS" 
        # MTI-630(R) and Sirius/Avior AHRS models, yaw has 3 options: "FixedMagRef", "NorthReference", "VRU", "VRUAHS" 
        filter_label_yaw: "NorthReference"
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

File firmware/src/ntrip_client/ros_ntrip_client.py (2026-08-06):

#!/usr/bin/env python3

import base64
import math
import os
import select
import socket
import threading
import time
from datetime import datetime, timezone

import rclpy
from rclpy.node import Node
from sensor_msgs.msg import NavSatFix
import serial


class RosNtripClient(Node):
    def __init__(self) -> None:
        super().__init__("ntrip_client")

        self.declare_parameter("host", "opencaster.nls.fi")
        self.declare_parameter("port", 2101)
        self.declare_parameter("mountpoint", "VRS-FKP")
        self.declare_parameter("navsatfix_topic", "/Gnss/navsatfix")
        self.declare_parameter("serial_port", "/dev/gps-ntrip")
        self.declare_parameter("serial_baudrate", 115200)
        self.declare_parameter("gga_interval", 5.0)
        self.declare_parameter("reconnect_delay", 5.0)

        self.host = str(self.get_parameter("host").value)
        self.port = int(self.get_parameter("port").value)
        self.mountpoint = str(self.get_parameter("mountpoint").value)
        self.serial_port = str(self.get_parameter("serial_port").value)
        self.serial_baudrate = int(self.get_parameter("serial_baudrate").value)
        self.gga_interval = float(self.get_parameter("gga_interval").value)
        self.reconnect_delay = float(self.get_parameter("reconnect_delay").value)

        self.username = os.environ.get("NTRIPUSER")
        self.password = os.environ.get("NTRIPPASS")

        if not self.username or not self.password:
            raise RuntimeError("NTRIPUSER and NTRIPPASS must be set in the environment")

        self.position_lock = threading.Lock()
        self.latest_fix: NavSatFix | None = None
        self.running = True

        topic = str(self.get_parameter("navsatfix_topic").value)
        self.subscription = self.create_subscription(
            NavSatFix,
            topic,
            self.fix_callback,
            10,
        )

        self.worker = threading.Thread(
            target=self.connection_loop,
            daemon=True,
        )
        self.worker.start()

        self.get_logger().info(
            f"Waiting for position on {topic}; RTCM output: {self.serial_port}"
        )

    def fix_callback(self, message: NavSatFix) -> None:
        if (
            not math.isfinite(message.latitude)
            or not math.isfinite(message.longitude)
            or not math.isfinite(message.altitude)
        ):
            return

        # status < 0 means no position fix.
        if message.status.status < 0:
            return

        with self.position_lock:
            self.latest_fix = message

    @staticmethod
    def decimal_to_nmea(
        value: float,
        is_latitude: bool,
    ) -> tuple[str, str]:
        absolute = abs(value)
        degrees = int(absolute)
        minutes = (absolute - degrees) * 60.0

        if is_latitude:
            coordinate = f"{degrees:02d}{minutes:09.6f}"
            hemisphere = "N" if value >= 0 else "S"
        else:
            coordinate = f"{degrees:03d}{minutes:09.6f}"
            hemisphere = "E" if value >= 0 else "W"

        return coordinate, hemisphere

    @staticmethod
    def add_checksum(sentence_body: str) -> str:
        checksum = 0

        for character in sentence_body:
            checksum ^= ord(character)

        return f"${sentence_body}*{checksum:02X}\r\n"

    def make_gga(self, fix: NavSatFix) -> str:
        latitude, north_south = self.decimal_to_nmea(
            fix.latitude,
            is_latitude=True,
        )
        longitude, east_west = self.decimal_to_nmea(
            fix.longitude,
            is_latitude=False,
        )

        timestamp = datetime.now(timezone.utc).strftime("%H%M%S.00")

        # For VRS selection, the important fields are time and position.
        # Quality 1 means a valid autonomous GNSS fix.
        body = (
            f"GPGGA,{timestamp},"
            f"{latitude},{north_south},"
            f"{longitude},{east_west},"
            f"1,08,1.0,"
            f"{fix.altitude:.3f},M,"
            f"0.0,M,,"
        )

        return self.add_checksum(body)

    def make_request(self) -> bytes:
        credentials = f"{self.username}:{self.password}"
        authorization = base64.b64encode(credentials.encode("utf-8")).decode("ascii")

        request = (
            f"GET /{self.mountpoint} HTTP/1.1\r\n"
            f"Host: {self.host}:{self.port}\r\n"
            "Ntrip-Version: Ntrip/2.0\r\n"
            "User-Agent: NTRIP ros2-live-gga/1.0\r\n"
            f"Authorization: Basic {authorization}\r\n"
            "Connection: close\r\n"
            "\r\n"
        )

        return request.encode("ascii")

    @staticmethod
    def read_response_headers(connection: socket.socket) -> bytes:
        received = bytearray()

        while b"\r\n\r\n" not in received:
            chunk = connection.recv(1)

            if not chunk:
                raise ConnectionError("Caster closed connection during handshake")

            received.extend(chunk)

            if len(received) > 16384:
                raise ConnectionError("NTRIP response headers too large")

        return bytes(received)

    @staticmethod
    def response_is_successful(headers: bytes) -> bool:
        first_line = headers.split(b"\r\n", 1)[0]

        return b"200 OK" in first_line or first_line.startswith(b"ICY 200")

    def get_latest_fix(self) -> NavSatFix | None:
        with self.position_lock:
            return self.latest_fix

    def connect_once(self) -> None:
        # Wait until the receiver has produced its own initial position.
        while self.running and rclpy.ok():
            fix = self.get_latest_fix()

            if fix is not None:
                break

            time.sleep(0.25)

        if not self.running or not rclpy.ok():
            return

        self.get_logger().info(
            f"Connecting to {self.host}:{self.port}/{self.mountpoint}"
        )

        with serial.Serial(
            port=self.serial_port,
            baudrate=self.serial_baudrate,
            bytesize=serial.EIGHTBITS,
            parity=serial.PARITY_NONE,
            stopbits=serial.STOPBITS_ONE,
            timeout=1.0,
            write_timeout=2.0,
        ) as receiver_serial:
            with socket.create_connection(
                (self.host, self.port),
                timeout=15.0,
            ) as caster:
                caster.settimeout(None)
                caster.sendall(self.make_request())

                headers = self.read_response_headers(caster)

                if not self.response_is_successful(headers):
                    first_line = headers.split(b"\r\n", 1)[0]
                    raise ConnectionError(
                        f"NTRIP connection rejected: "
                        f"{first_line.decode(errors='replace')}"
                    )

                self.get_logger().info("NTRIP connection established")
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

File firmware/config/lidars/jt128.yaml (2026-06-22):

lidar:
  - driver:
      use_gpu: false
      source_type: 1                                  # The type of data source, 1: real-time lidar connection, 2: pcap, 3: packet rosbag, 4: serial    
      # Depending on the type of source_type, fill in the corresponding configuration block (lidar_udp_type, pcap_type, serial_type)
      lidar_udp_type:
        device_ip_address: "192.168.1.201"            # host_ip_address. If empty(""), the source ip of the udp point cloud is used
        udp_port: 2368                                # UDP destination port
        ptc_port: 9347                                # PTC port of lidar
        multicast_ip_address: ""

        use_ptc_connected: true                       # Set to false when ptc connection is not used
        host_ptc_port: 0                              # PTC source port, 0 means auto
        correction_file_path: "/ros2_ws/config/correction_files/JT128_default_angle.csv"   # The path of correction file
        firetimes_path: ""                            # The path of firetimes file

        recv_point_cloud_timeout: -1                  # The timeout of receiving point cloud
        ptc_connect_timeout: -1                       # The timeout of ptc connection

        host_ip_address: "192.168.1.2"
        fault_message_port: 0

        standby_mode: 0                               # The standby mode: [-1] is invalit [0] in operation [1] standby
        speed: 1200                                   # The speed: [-1] invalit, you must make sure your set has been supported by the lidar you are using
        ptc_mode: 0                                   # The ptc mode: [0] tcp [1] tcp_ssl
        # tcp_ssl use
        certFile: ""                                  # Represents the path of the user's certificate
        privateKeyFile: ""                            # Represents the path of the user's private key 
        caFile: ""                                    # Represents the path of the CA certificate 
      
      # public module
      use_timestamp_type: 0                 # 0 use point cloud timestamp; 1 use receive timestamp
      frame_start_azimuth: 0                # Frame azimuth for Pandar128, range from 1 to 359, set it less than 0 if you do not want to use it      
      # parser thread num
      thread_num: 4
      # transform param
      transform_flag: false
      x: 0
      y: 0
      z: 0
      roll: 0
      pitch: 0
      yaw: 0
      # fov config, [fov_start, fov_end] range [1, 359], [-1, -1]means use default
      fov_start: -1
      fov_end:  -1
      channel_fov_filter_path: ""  # The path of channel_fov_filter file, like channel 0 filter [10, 20] and [30,40]
      multi_fov_filter_ranges: "" # compare to channel_fov_filter_path, multi_fov_filter_ranges for all channels. example config "[20,30];[40,200]"
      # other config
      enable_packet_loss_tool: false        # enable the udp packet loss detection tool
      distance_correction_flag: false       # set to true when optical centre correction needs to be turned on
      xt_spot_correction: false             # Set to TRUE when XT S point cloud layering correction is required
      device_udp_src_port: 0                # Filter point clouds for specified source ports in case of multiple lidar, setting >=1024
      device_fault_port: 0                  # Filter fault message for specified source ports in case of multiple lidar, setting >=1024
      frame_frequency: 10                   # The frequency that point cloud sends.
      default_frame_frequency: 10.0         # The default frequency that point cloud sends.
      echo_mode_filter: 0                   # return mode filter
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

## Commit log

2026-06-01 Added instructions on LIDAR-usage to the project readme
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2026-06-05 Reworked the mechanical assembly now that AutoVimation finally gave us model access
    [Autovimation_colibriS.FCStd, Autovimation_orca_m.FCStd, Basler_mount_front_NIR.FCStd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]
2026-06-08 Finalized the mechanical design
    [Hesai_XT32.FCStd, Hesai_xt32_mount.FCStd, Low_poly_aluminum_extrusions.FCStd]
2026-06-08 Fixed corner brackets to be counted correctly for BOM
    [1.3022 Kulma 45.FCStd]
2026-06-08 generated BOM of assembly
    [Basler_mount_front_NIR.FCStd, Hesai_XT32.FCStd, Hesai_jt128_mount.FCStd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]
2026-06-08 Add correct window to rgb cameras... thanks autovimation
    [Autovimation_colibriS.FCStd]
2026-06-09 Added corner brackets, extended lidar plate and crashed freecad once
    [1.3022 Kulma 45.FCStd, 1.3060 Kulmalevy.FCStd, 1.3060_Kulmalevy.FCStd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]
2026-06-09 added end caps
    [1.1063_paatysuoja.FCStd, 1.3060 Kulmalevy.FCStd]
2026-06-12 Add dc converters, redo right camera mount plate, double check hole alignment on dome
    [1.3022 Kulma 45.FCStd, 1.3028_Kulma_45X90.FCStd, 1.3060_Kulmalevy.FCStd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]
2026-06-12 Add technical drawings to freecad files
    [1.1063_paatysuoja.FCStd, 1.3022 Kulma 45.FCStd, 1.3028_Kulma_45X90.FCStd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]
2026-06-22 Add lidar configuration files and launch script for Hesai driver
    [XT_Angle_Correction.csv, XT_Firetime_Correction.csv]
2026-06-22 Add lidar driver configuration and correction files for JT128
    [JT128_default_angle.csv]
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2026-06-22 Slight rework of configs to allow both lidars to be displayed simultaniously
2026-06-22 Rename lidar file to view instead of launch
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2026-06-22 Added IMU-data recording to the existing rosbag implementation, removed unused rviz-lines.
2026-06-22 Move the lidar scripts into a testing folder so that they still exist if needed. Rewrite lidar code for proper ros node in main based on these
2026-06-24 Removed unused manufacturer drivers (LIDARs, IMU, GPS) and trimmed the readme guide
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2026-06-25 rework dc-converter plate to fit in water jet cutter. Couple new cabinet possibilities
    [DC-DC_rectangle.FCStd, DC-DC_square.FCStd, Electronics_box.FCStd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]
2026-06-25 Setup systemd service which starts the containers and ros2 package on boot so that the whole system is ready to use after power on.
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2026-07-06 Switch to argparse instead of ros args as this will be raw python and not packaged ros
2026-07-06 Switch to python argparse instead of ros args as this is raw python and not packaged ros. Also fix formatting
2026-07-08 Add data collection to bringup !!CAREFUL LIDARS NOW START DUMPING DATA WHEN CONTAINER STARTS!!
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2026-07-20 Ublox antenna stuff
    [Ublox_antenna.FCStd, YA_elec_cabinet.FCStd, ublox_antenna_assembly.FCStd]
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2026-07-20 Add led control logic to mirror status page
2026-07-20 Hesai lidars dont publish /diagnostics topic so make a quick own version which subs to points and loss and send those to webui. Change ptp status on webui to loss
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2026-07-20 Fix lidar HZ calculation
    [app.py, lidar_diagnostics.py]
2026-07-21 Add custom names for devices on the sensor list
2026-07-21 Add gps fix type to ui
    [gps_diagnostics.py]
2026-07-21 fix bringup and camera configs in webui
2026-07-21 The gnss board needs an wifi extension addon to be able to use built in ntrip client. So we will broadcast the client data from the NUC instead
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2026-07-22 Fix camera mtu size
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2026-07-29 Add camera intrinsic and extrinsic calibration packages to ros
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2026-07-29 First implementation on extrinsic LIDAR/LIDAR and LIDAR/Camera calibration
    [Radas_calibration_target_mesh.ply]
2026-07-29 First iteration of camera intrinsics calibration
    [Calibration_target.FCStd, Radas_calibration_target_mesh.ply, Radas_calibration_target_mesh_3mm.ply]
2026-07-29 First iteration of jt point cloud correction
    [jt_calibration.yaml]
2026-07-29 Update calibration target cad model
    [Calibration_target.FCStd, Radas_calibration_target_mesh.ply]
2026-07-29 Fix 10^x error on calibration ply files scale
    [Radas_calibration_target_mesh.ply, Radas_calibration_target_mesh_3mm.ply]
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2026-07-29 Make a 3 hole variant of calibration target for asymmetric detection
    [Calibration_target.FCStd, Radas_calibration_target_mesh_3hole.ply]
2026-07-29 Fixed lidar-to-lidar extrinsic calibration
    [jt_calibration.yaml]
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2026-07-29 Decided to always use raw point cloud from jt for calibration instead of having to do matrix multiplication on new and current translation and quaternion rotation calibration matrixes
2026-07-29 Fix target file to work with the aruco markers on our calibration board
    [TargetWithCirclesAndAruco.yaml]
2026-07-29 Implemented calibration result saving on extrinsic camera calibration and added more detail to calibration.md
2026-07-29 Fix region of interest on the cameras on startup
2026-07-29 Automatically move instrinsics calibration results to correct folder in config
2026-07-29 First iteration of xsens enclosure
    [Xsens_enclosure-Xsens_enclosure_base.step, Xsens_enclosure.FCStd]
2026-07-29 change hole dimension for enclosure and make a lid
    [Xsens_enclosure-Xsens_enclosure_base.step, Xsens_enclosure-Xsens_enclosure_lid.step]
2026-07-29 v3 of xsens enclosure with tighter tolerances and smaller cable hole
    [Xsens_enclosure-Xsens_enclosure_base.step, Xsens_enclosure-Xsens_enclosure_lid.step, Xsens_enclosure.FCStd]
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2026-07-29 Implemented using an initial guess in the calibration
2026-07-29 Baseline calibration for cameras
    [last_left_calib.yaml, last_middle_calib.yaml, last_right_calib.yaml]
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2026-07-30 Quick dirty shell script to use hardware trigger on a camera
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2026-07-31 Remove mugshots and 4 hole target files as 3 hole works better
    [Radas_calibration_target_mesh.ply]
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2026-08-03 Fixed syntax-error and a package mislabel preventing driver launch. Removed unused data-collection and ptp-configuration processes
2026-08-04 Designed mounting hardware for the inside of the electrical cabinet
    [YA_elec_cabinet.FCStd, base_mount_plate.FCStd, nuc_mount_bottom.FCStd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]
2026-08-05 tweak models after printing
    [nuc_mount_top.FCStd, router_mount.FCStd]
2026-08-06 Fix camera configurator issues
2026-08-06 Fix gps device id possibly changing on system restart
    [custom_rover.yaml, ros_ntrip_client.py]
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2026-08-06 Move calibration configurations into own subfolder
    [Radas_calibration_target_mesh_3hole.ply]
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2026-08-06 move jt calibration to extrincis
    [jt_calibration.yaml]
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2026-08-06 remove start grabbing from camera config as its automatically called by roi
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2026-08-07 Remove nir from sensor list and update IMU to the one used
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2026-08-10 Tweak antenna plate before manufacturing
    [ublox_antenna_assembly.FCStd]
2026-08-10 Make antenna plate attachement holes tappable
    [ublox_antenna_assembly.FCStd]
2026-08-10 "wrong hole" :D
    [ublox_antenna_assembly.FCStd]
2026-08-10 Couple config fixes
2026-08-10 Fix .venv version used in camera config and ntrip
2026-08-11 Fix msg type formatting
    [bag_manager.py]
2026-08-11 Fix imu/mag output
2026-08-11 Change converter mount plate to be countersunk
    [converter_mount.FCStd]
2026-08-12 First iter of dome guard attachement
    [Hesai_jt128_mount.FCStd, Jt_guard_mount.FCStd]
2026-08-13 Fix imu pretty name
    [app.py]
2026-08-13 Fix for low imu datarate see #9
2026-08-13 Correct the expected imu datarate (numbers show fused rate with magnetometer, other 6 axis are still 1kHz)
    [app.py, imu_diagnostics.py]
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2026-09-14 Uhh some changes to the mechanical design. Should have probs committed these before holidays but oh well
    [YA_elec_cabinet.FCStd, base_mount_plate.FCStd, router_mount.FCStd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]
2026-09-24 fusebox modelled
    [dome_guard.FCStd, fusebox.FCStd]
2026-11-05 IMU datarate issue fixed driver side, Fixes #9
